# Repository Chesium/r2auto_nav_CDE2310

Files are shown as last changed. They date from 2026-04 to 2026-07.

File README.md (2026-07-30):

# CDE2310 System Engineering - AY2526 Group 3

- **Team Member:** Chen Shimin, Seow Cheng Si, Arnav Jhajharia, Abhinandan Shrimal, Daphne Shaine Wilhelmina
- **Final Grade: A-**

An autonomous TurtleBot3-based delivery robot built for the CDE2310/EG2310 robotics course at the National University of Singapore.

The robot was designed to explore an unknown maze, identify two target stations, dock using visual feedback, align a ping-pong-ball launcher with each receptacle, and fire three balls per station within a 25-minute mission window.

Course page: [CDE2310/EG2310 AY2526](https://blog.nus.edu.sg/eg2310/2026-2/)

## Final Run (14 April 2026, Week 13 Tue)

- [Final run screen recording, part 1](https://www.youtube.com/watch?v=hjtmTSh4A78)
- [Final run screen recording, part 2](https://www.youtube.com/watch?v=OZwQptIx55s)

The final run did not reflect the system we hoped to demonstrate. Our team ended up with the lowest final-run score, mainly because the frontier mapping and Nav2 mission flow did not come together reliably during full-system integration. That result was disappointing, but it also made the project a useful record of what worked, what did not, and what we would do differently.

Despite the difficult final demonstration, the project was still valuable. I eventually received an A- for the course, and I suspect the documentation and engineering reflection captured in this repository helped compensate for the weak final run. I entered the course without a Nav2 background, and the work here gave me practical experience with ROS 2 navigation, frontier exploration, simulation, robot networking, and system integration. That experience later helped me secure my first robotics-navigation internship at [Griffin Labs](https://griffinlabs.ai/). The course experience was rough, but the learning was real.

- Frontier Exploration Demo In Simulation (20 March 2026, Week 9 Fri)

https://github.com/user-attachments/assets/755e566e-a58e-4059-8860-4c8718844997

- Turtlebot Navigation Demo Video (21 March 2026, Week 9 Sat)

https://github.com/user-attachments/assets/281b9f60-19b3-4af7-8525-cc15e1a01227

## System Overview

The platform extends a TurtleBot3 Burger with a Raspberry Pi, LiDAR, USB/RPi camera sensing, a custom mechanical ball launcher, and ROS 2 software running across robot and laptop/container environments.

At a high level, the system is organized into:

| Layer | Main components | Purpose |
| --- | --- | --- |
| Mission control | `g3_mission_control` | Finite-state mission sequencing, retries, station tracking, launcher coordination |
| Navigation | Nav2, SLAM, `g3g_frontier_exploration`, `g3nav2` | Autonomous exploration, path planning, obstacle avoidance, hardware Nav2 configuration |
| Perception and docking | `g3_visual_servo`, ArUco markers, station aligners | Station detection, short-range docking, receptacle alignment |
| Actuation | `g3_ball_launcher`, TurtleBot3 motor control | UART servo-based ball launching and base motion |
| Simulation and assets | `g3gzsim`, Gazebo Harmonic worlds, CAD files | Local testing, subsystem validation, mechanical design references |

The final mission concept was:

1. Start the robot and verify required services.
2. Explore the unknown arena using frontier-based exploration.
3. Detect Station A or Station B using ArUco markers.
4. Pause exploration and dock using visual servoing.
5. Align the launcher to the receptacle.
6. Fire three ping-pong balls.
7. Resume exploration until both stations are completed.

## Repository Map

| Path | Description |
| --- | --- |
| [`src/g3_mission_control`](src/g3_mission_control) | Python FSM controllers for the competition mission and simplified debug flow |
| [`src/g3g_frontier_exploration`](src/g3g_frontier_exploration) | Frontier selection and Nav2 goal dispatch for autonomous exploration |
| [`src/g3_visual_servo`](src/g3_visual_servo) | ArUco marker detection, pose publishing, and visual-servo docking experiments |
| [`src/g3_aligner`](src/g3_aligner) | Station alignment nodes using camera feedback and Hough-circle style target detection |
| [`src/g3_ball_launcher`](src/g3_ball_launcher) | Ball launcher node and UART servo SDK |
| [`src/g3gzsim`](src/g3gzsim) | Gazebo worlds, models, RViz configs, and simulation launch files |
| [`src/g3nav2`](src/g3nav2) | Nav2 launch and configuration for TurtleBot3 hardware |
| [`docker`](docker) | Portable ROS 2 Jazzy, Gazebo, Nav2, and Foxglove development environment |
| [`docs`](docs) | Course report pages, development guide, user manual, and subsystem documentation |
| [`obsidian-vault`](obsidian-vault) | Additional architecture notes, package references, and how-to material |
| [`mech`](mech) | Mechanical photos, launcher videos, drawings, and CAD files |

## Quick Start

The recommended development path is the Docker environment, which provides ROS 2 Jazzy, Gazebo Harmonic, Nav2, Cartographer, Foxglove bridge, and TurtleBot3 dependencies.

```bash
docker compose build
docker compose -f docker-compose.yml -f docker-compose.wslg.yml up -d
docker compose -f docker-compose.yml -f docker-compose.wslg.yml exec dev bash
```

Inside the container:

```bash
cd ~/nav_ws
colcon build --symlink-install
source install/setup.bash
ros2 launch g3gzsim nav2full_test_launch.py
```

To activate frontier exploration from another terminal:

```bash
ros2 service call /exploration/set_enabled std_srvs/srv/SetBool "{data: true}"
```

For host-specific setup, real-robot networking, camera launch commands, Foxglove, and Nav2 notes, see the [Development Guide](docs/DevelopmentGuide.md).

## Project Artifacts

- [User Manual](docs/assets/g2-report/Group3_User_Manual.pdf)
- [Development Guide](docs/DevelopmentGuide.md)
- [Architecture Overview](obsidian-vault/architecture/Architecture%20Overview.md)
- [ROS 2 Topic and Service Map](obsidian-vault/architecture/ROS2%20Topic%20and%20Service%20Map.md)
- [Package Index](obsidian-vault/packages/Package%20Index.md)

## Report Pages

- [Requirement Specifications](docs/G2-Requirement-Specifications.md)
- [Con-Ops](docs/G2-Con-Ops.md)
- [High-Level Design](docs/G2-High-Level-Design.md)
- Subsystem Design
  - [Launcher & Servo](docs/G2-Launcher-Servo.md)
  - [Visual Servo & ArUco Docking](docs/G2-Visual-Servo.md)
  - [Autonomous Exploration and Navigation](docs/G2-Autonomous-Exploration-and-Navigation.md)
  - [Receptacle Alignment](docs/G2-Alignment.md)
- [Interface Control Document](docs/G2-Interface-Control-Document.md)
- [Software Development Documentation](docs/G2-Software-Development-Documentation.md)
- [Testing Documentation](docs/G2-Testing-Documentation.md)
- [Areas for Improvement](docs/G2-Areas-for-Improvement.md)

## Mechanical Media

- [Front view](mech/front_view.jpg)
- [Back view](mech/back_view.jpg)
- [Side view](mech/side_view.jpg)
- [Launcher in action](mech/launcher_in_action.mp4)
- [Cam animation](mech/cam_animation.mp4)
- [Mechanical drawings](mech/drawings)
- [CAD files](mech/cad_files)

## Retrospective

Our early progress was stronger than the final result suggests. The team started ahead of average in preparation, assignments, and initial subsystem work. The navigation stack was completed and tested relatively early, and the project also produced a large amount of documentation, simulation work, CAD, and subsystem code.

The main weakness was integration. From around the Preliminary Design Review onward, subsystem maturity and integration pace slowed. Several modules remained too isolated for too long, and we overestimated how naturally the final system would come together. When the final run arrived, the integration quality was not strong enough for the navigation, docking, alignment, and launching chain to perform reliably as one system.

The biggest lessons:

- Treat integration as a first-class task from the beginning, not a final-week activity.
- Define interface specifications, ownership boundaries, and system-level test plans early.
- Prototype a thin end-to-end mission flow before polishing individual subsystems.
- Hold more frequent technical design reviews and reallocate support when a subsystem falls behind.
- Set up Docker, ROS 2 networking, and lab debugging infrastructure early so everyone can test independently.
- Complete the full CAD assembly earlier, including electronics placement and mounting details, to reduce late mechanical redesigns.

The result was imperfect, but the repository preserves both the engineering attempt and the learning process behind it.

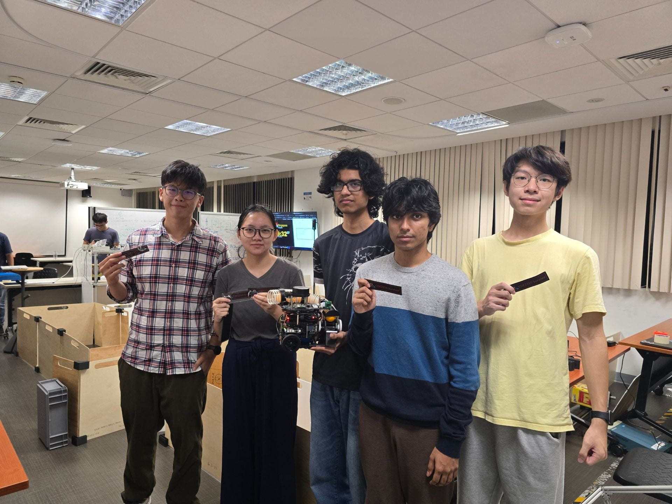
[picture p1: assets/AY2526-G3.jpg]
CDE2310 AY2526 Group 3 robot


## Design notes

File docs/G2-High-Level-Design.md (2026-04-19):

# High-Level Design

[Home](../README.md)

## Overall System Architecture

### Hardware and Electrical System Architecture

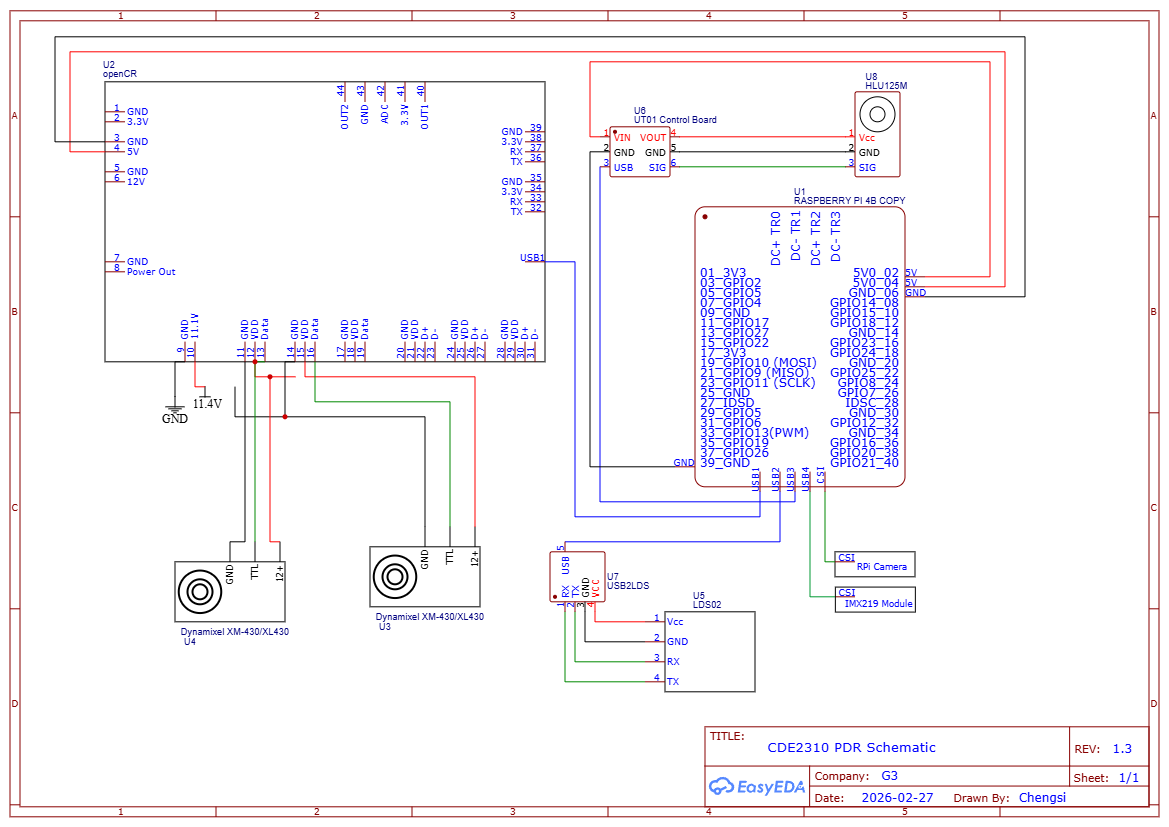
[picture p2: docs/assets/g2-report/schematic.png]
schematic


<p align="center">Fig: System schematic</p><br>

The hardware platform is based on a TurtleBot3 mobile base extended with onboard compute, camera sensing, launcher actuation, and supporting electrical subsystems. Power and signal routing are distributed across the Raspberry Pi, the OpenCR motor controller, and the attached peripheral devices. This modular arrangement allowed individual subsystems to be developed, tested, and replaced with minimal impact on the rest of the platform.

### Software Architecture

The software stack follows a modular ROS 2 node-based architecture. A central mission controller coordinates overall task sequencing, while specialised worker nodes handle docking, receptacle alignment, exploration, perception, and ball launching. The nodes communicate through ROS 2 topics and services, allowing each subsystem to be developed independently while maintaining clear runtime interfaces.

## Mission Logic Architecture Selection

An initial Behaviour Tree implementation using Groot2 and BehaviorTree.CPP was evaluated during early development. However, the final mission requirements were largely sequential and required limited interruption or dynamic replanning. In practice, the Behaviour Tree approach introduced additional implementation overhead, debugging complexity, and tooling instability relative to the project timeline.

The team therefore migrated to a Python-based finite state machine (FSM). This choice provided deterministic execution, faster implementation, and a simpler debugging workflow, while still matching the fixed sequence of tasks required by the competition.

## Mission Controller Design

### Overview

The mission controller (`mission_controller.py`) is the sole decision-making authority in the system. All other nodes act as specialised workers that publish observations or respond to service requests. The FSM runs at 10 Hz and coordinates the full delivery sequence across both stations. Long-range navigation is handled through exploration and Nav2, while close-range docking is delegated to the visual-servo subsystem based on ArUco pose estimation.

### FSM Graph

State flow: `INIT → EXPLORE → DOCK_AT_X → ALIGN_AT_X → FIRE_AT_X → COMPLETE`, with fallback transitions into `FAILED` for retry handling.

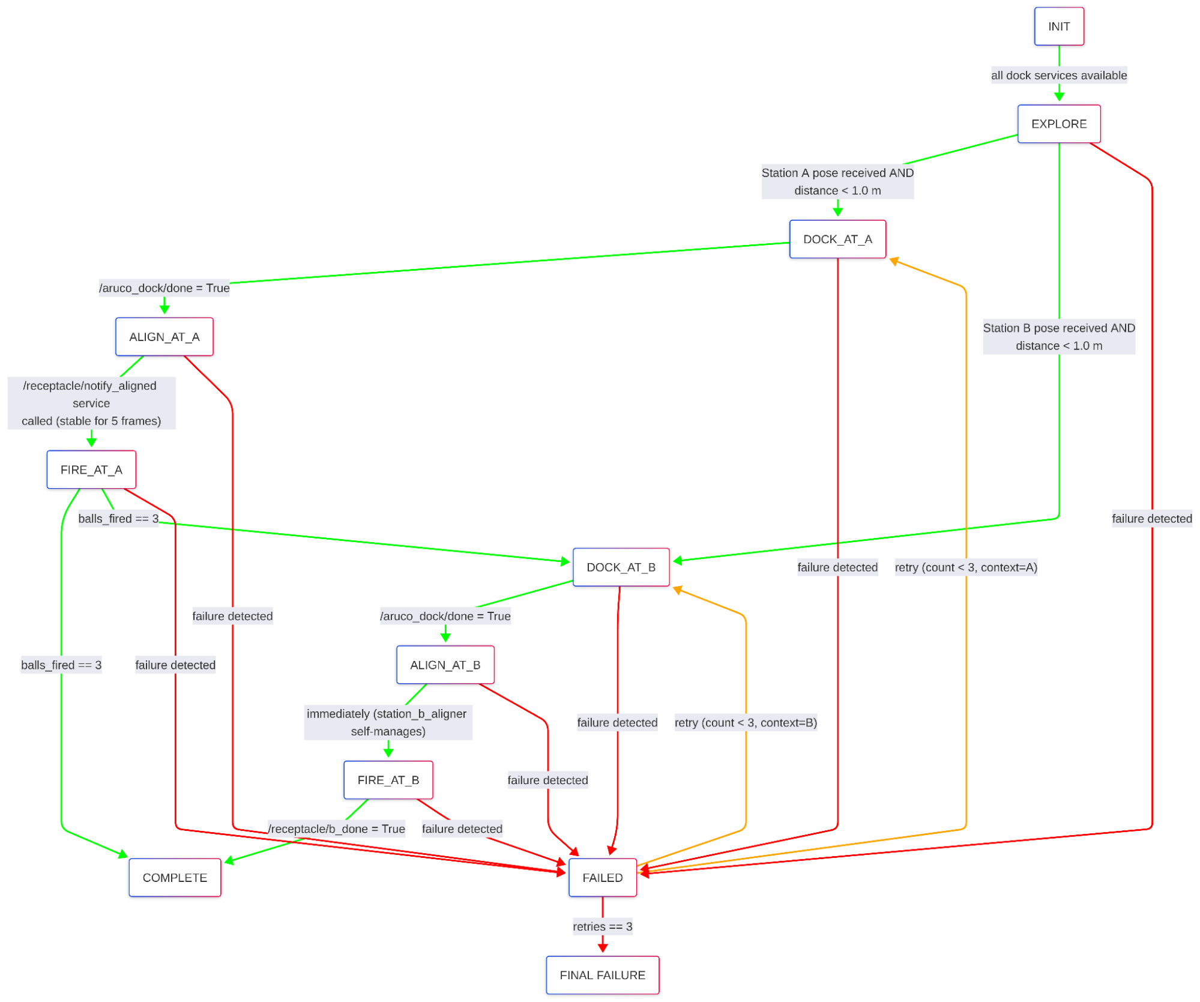
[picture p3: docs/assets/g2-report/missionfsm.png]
missionfsm


<p align="center">Fig: High-level mission controller FSM</p><br>

### Design Decisions and Rationale

| Decision | Rationale |
| --- | --- |
| Use visual servoing rather than Nav2 for final docking | Final approach is a short-range perception problem. ArUco-based visual servoing is less dependent on global localisation quality and avoids compounding map and pose error close to the target. |
| Run the FSM at 10 Hz rather than as a purely event-driven system | A fixed control tick simplifies timeout handling, keeps state transitions predictable, and reduces the likelihood of callback-order race conditions. |
| Allow Station B to trigger firing autonomously | The moving target at Station B requires a reactive trigger based on LED visibility. This response is more reliable when handled directly by the aligner than by a slower supervisory loop. |
| Expose timing values as ROS 2 parameters | Timing constraints changed during development. Parameterisation allowed the team to update mission behaviour without editing code or rebuilding the software stack. |

### Fault Handling and Robustness Strategy

The mission controller incorporates timeout detection, retry limits, and fallback transitions. If docking or alignment fails repeatedly at a given station, the controller can skip that station and continue with the remaining objectives where possible. This design reduces the risk that a single subsystem failure will terminate the entire mission.

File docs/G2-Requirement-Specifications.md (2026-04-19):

# Requirement Specifications

[Home](../README.md)

The G2 mission allocates 25 minutes for setup, execution, and teardown. During the setup period, the team must place the required identification markers, position the robot in the start zone, prepare the operator computer and software stack, load the ping-pong balls, and complete any other pre-run activities. A user guide must also be provided for the teaching staff's reference. Once activated, the autonomous mobile robot must leave the start zone, enter the maze, build a map using LiDAR, and detect the landmarks required for task execution.

The robot must identify two primary stations, Station A (static) and Station B (dynamic), using the markers placed during setup. It must then dock within operational tolerance, align its launcher, and deliver three ping-pong balls to each receptacle. The platform must carry at least nine ping-pong balls, and it may retry a shot if an unloading error occurs. At Station A, the robot must fire into a fixed receptacle of approximately 65 mm radius using a specified timing pattern. At Station B, the target receptacle moves on a motorised linear rail, so the robot must identify the marker, infer the motion timing, and coordinate docking and firing accordingly. After completing delivery, the robot must either continue to the next objective or conclude the mission. Official mission timing stops once the second unloading task is completed.

The bonus mission extends the task to Stations C and D. For this stage, the robot must navigate to the lift lobby using land-based QR markers, detect Station C, issue the required API call to summon the lift, enter the lift safely after arrival is confirmed, and send the appropriate command to travel to Level 2. It must then leave the lift, navigate to Station D, and unload into a fixed receptacle. At the end of the 25-minute window, the team must clear all materials from the arena. Scoring is based not only on payload delivery, but also on completion time and map closure, with additional credit awarded for single-launch ROS 2 deployment and ROS bag recording.

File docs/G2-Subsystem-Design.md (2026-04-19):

# Subsystem Design

[Home](../README.md)

## Launcher & Servo

The ball launcher uses a 25 kg-cm JOHO UART bus servo operated in DC motor mode, controlled by the `ball_launcher_node.py` in the `g3_ball_launcher` package. The node communicates with the servo over a USB-to-UART adapter at 115200 bps using a bundled Python SDK (`uart_sdk/`) that implements the JOHO packet protocol. On startup, the node sets the servo to DC mode (`MOTOR_MODE_DC = 0x00`), spins CW at low speed to find the init position (`CURRENT_POSITION = 4000`), then stops and reports idle. When /fire_launcher is called, a daemon thread calls `dc_rotate(CW, 100%)` to spin the motor at full PWM for 2.2 seconds, then `dc_stop()` to stop the motor. The status cycles through `idle → firing → complete → idle`, with the complete state held briefly so the mission controller can read it via the /launcher_status topic at 10 Hz. Thread safety is handled with two locks (`_lock` for status, `_serial_lock` for UART) and a `threading.Event` for stop requests.

Mechanical Subsystem Drawings

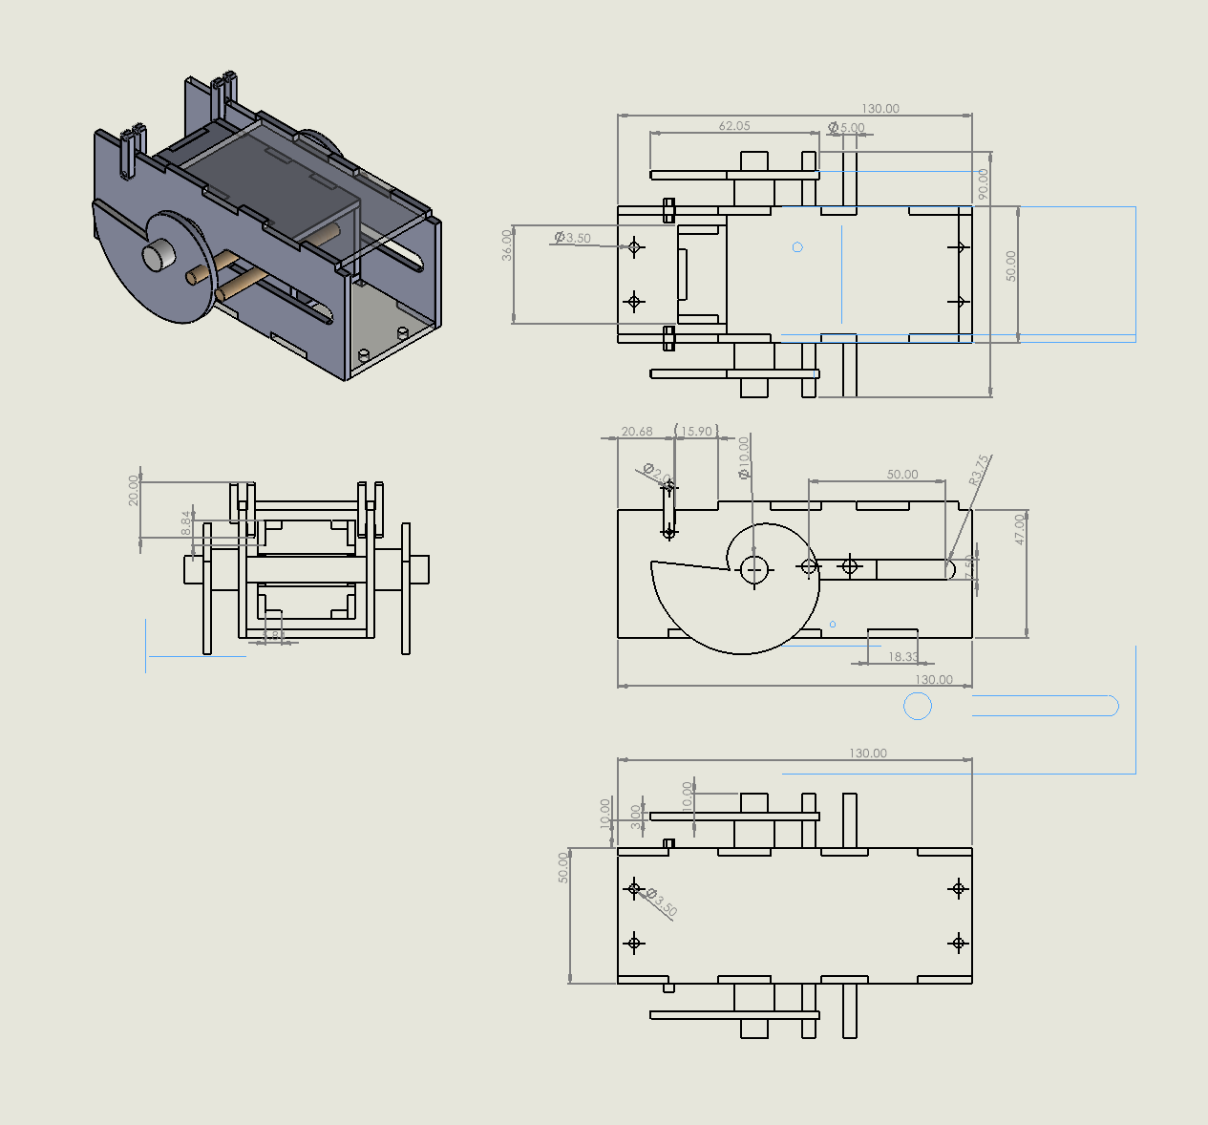
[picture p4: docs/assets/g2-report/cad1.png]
cad1


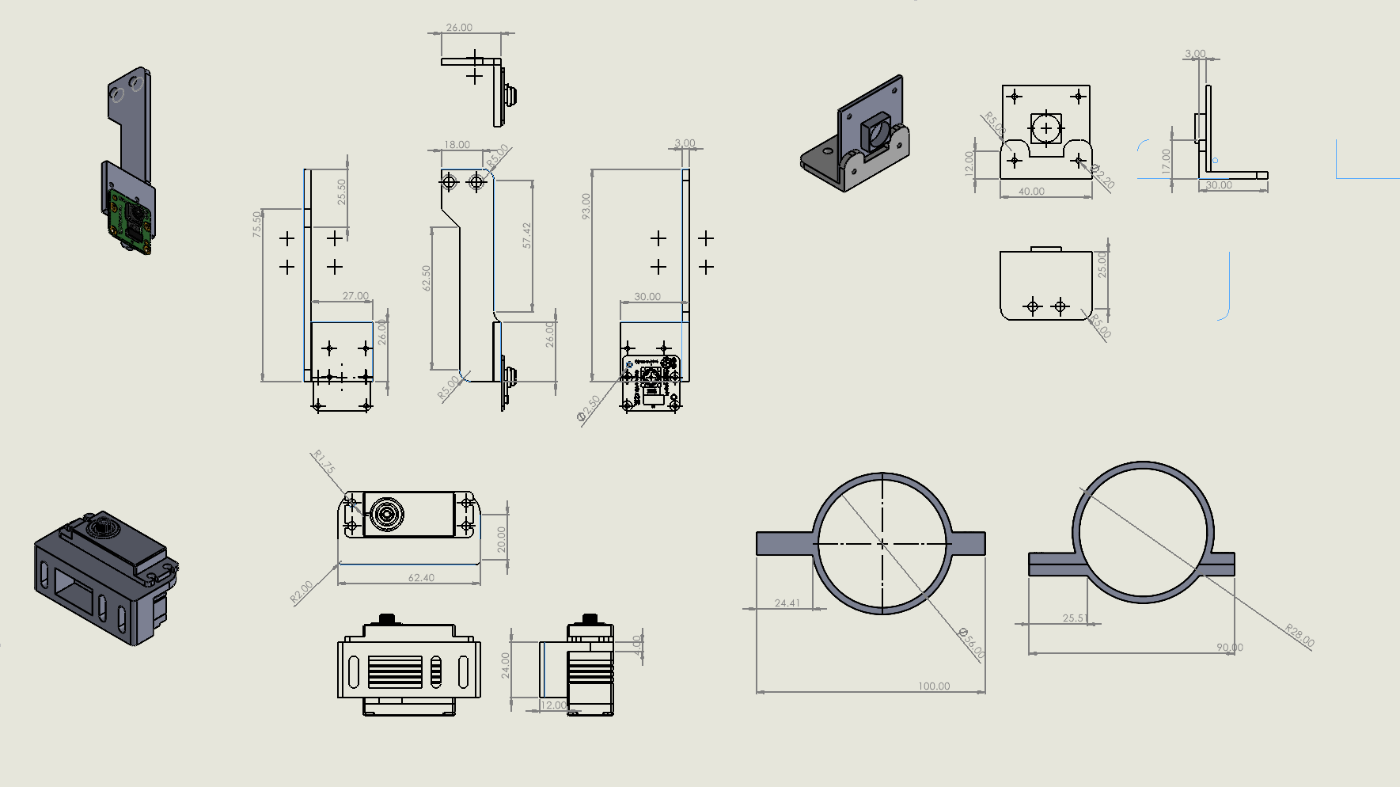
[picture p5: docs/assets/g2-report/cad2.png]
cad2


## Visual Servo/ Aruco Docking

### Overview

The algorithm uses solvePnP to do thi

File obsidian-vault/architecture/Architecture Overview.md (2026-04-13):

# Architecture Overview

## System Layers

```
┌─────────────────────────────────────────────────────┐
│                   MISSION LAYER                      │
│  mission_controller / simple_mission_fsm             │
│  (orchestrates the entire operation)                 │
├─────────────────────────────────────────────────────┤
│                 PERCEPTION LAYER                     │
│  aruco_dock_node     station_a_aligner               │
│  (camera → marker    (camera → Hough circle          │
│   detection + servo)  detection + P-control)          │
├─────────────────────────────────────────────────────┤
│                 NAVIGATION LAYER                     │
│  Nav2 stack          frontier_explorer               │
│  (path planning,     (autonomous exploration         │
│   obstacle avoid)     of unknown space)               │
├─────────────────────────────────────────────────────┤
│                  ACTUATION LAYER                     │
│  ball_launcher_node  /cmd_vel → motors               │
│  (UART servo for     (TurtleBot3 motor driver)       │
│   ball shooting)                                     │
├─────────────────────────────────────────────────────┤
│                  HARDWARE/SIM                        │
│  TurtleBot3 Burger   Gazebo Harmonic                 │
│  RPi + LiDAR + USB   (simulated world + sensors)     │
│  camera + servo                                      │
└─────────────────────────────────────────────────────┘
```

## Node Communication Graph

```mermaid
graph TB
    subgraph Mission
        MC[mission_controller]
        SFSM[simple_mission_fsm]
    end
    
    subgraph Perception
        ADN[aruco_dock_node]
        APP[aruco_dock_pose_publisher]
        SA[station_a_aligner]
    end
    
    subgraph Navigation
        NAV2[Nav2 Stack<br/>planner/controller/BT]
        FE[frontier_explorer]
        DS[docking_server]
    end
    
    subgraph Actuation
        BL[ball_launcher_node]
    end
    
    subgraph Sensors
        CAM[USB Camera]
        LIDAR[LiDAR]
    end
    
    CAM -->|/usb_cam/image_raw| ADN
    CAM -->|/camera/image_raw| APP
    CAM -->|/camera/image_raw/compressed| SA
    LIDAR -->|/scan| NAV2
    
    ADN -->|/station_a_pose<br/>/station_b_pose| MC
    ADN -->|/station_a_pose| SFSM
    ADN -->|/aruco_dock/done| SFSM
    ADN -->|/cmd_vel| Motors
    
    APP -->|/detected_dock_pose| DS
    
    SA -->|/receptacle/offset<br/>/receptacle/aligned| MC
    SA -->|/cmd_vel| Motors
    
    MC -->|NavigateToPose action| NAV2
    MC -->|/fire_launcher service| BL
    
    SFSM -->|/exploration/set_enabled| FE
    SFSM -->|/aruco_dock/dock_to_a| ADN
    
    FE -->|NavigateToPose action| NAV2
    
    BL -->|/launcher_status| MC
```

## Two Mission Controller Variants

### 1. `mission_controller.py` (Full competition FSM)
- Written by Daphne
- Handles: Explore -> Navigate -> Align -> Fire -> repeat
- Uses Hough circle alignment (`station_a_aligner`)
- Controls ball firing with timing delays
- 11 states, retry logic, full competition flow

### 2. `simple_mission_fsm.py` (Teaching/debug FSM)
- Minimal 4-state FSM: INIT -> EXPLORE -> DOCK -> DONE
- Coordinates frontier_explorer + aruco_dock_node
- Clean example of FSM design patterns
- Good for understanding the system without competition complexity

## Two Docking Approaches

### Legacy: `aruco_dock_node.py`
- Custom PI control loop
- Publishes `/cmd_vel` directly
- States: IDLE -> SCANNING -> APPROACHING -> DONE
- Triggered via `/aruco_dock/dock_to_a` service

### New (Nav2): `aruco_dock_pose_publisher.py` + `docking_server`
- Just publishes marker pose to `/detected_dock_pose`
- Nav2's `opennav_docking` handles the actual approach
- Uses `SimpleNonChargingDock` plugin
- Triggered via `/dock_robot` action

---

**See also:** [[ROS2 Topic and Service Map]], [[State Machine Reference]]

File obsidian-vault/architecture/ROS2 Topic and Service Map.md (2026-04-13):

# ROS2 Topic and Service Map

## Topics

### Perception Topics

| Topic | Type | Publisher | Subscriber | Purpose |
|---|---|---|---|---|
| `/station_a_pose` | PoseStamped | aruco_dock_node | mission_controller, simple_mission_fsm | Robot's map-frame pose when marker 42 seen |
| `/station_b_pose` | PoseStamped | aruco_dock_node | mission_controller | Robot's map-frame pose when marker 67 seen |
| `/detected_dock_pose` | PoseStamped | aruco_dock_pose_publisher | Nav2 docking_server | Marker pose in camera frame for Nav2 docking |
| `/aruco_dock/done` | Bool | aruco_dock_node | simple_mission_fsm | Docking approach complete signal |
| `/aruco_debug/image_raw` | Image | aruco_dock_node | Foxglove | Debug overlay with marker detection |
| `/receptacle/offset` | Int32 | station_a_aligner | mission_controller | Pixel offset from center (9999 = not detected) |
| `/receptacle/aligned` | Bool | station_a_aligner | mission_controller | True when Hough circle centered |
| `/receptacle/tin_ready` | Bool | station_a_aligner | mission_controller | Same as aligned for Station A |
| `/receptacle/annotated` | Image | station_a_aligner | Foxglove | Debug overlay with Hough detection |

### Navigation Topics

| Topic | Type | Publisher | Subscriber | Purpose |
|---|---|---|---|---|
| `/cmd_vel` | TwistStamped or Twist | Nav2/aruco_dock/aligner | motor driver | Velocity commands |
| `/map` | OccupancyGrid | SLAM (Cartographer) | frontier_explorer, Nav2 | Occupancy grid map |
| `/scan` | LaserScan | LiDAR driver | SLAM, Nav2 costmaps | 2D laser scans |
| `/odom` | Odometry | motor driver | Nav2, SLAM | Wheel odometry |
| `/exploration/frontiers` | MarkerArray | frontier_explorer | RViz | Visualization of frontier cells |
| `/exploration/current_goal` | PoseStamped | frontier_explorer | RViz | Current exploration target |

### State/Status Topics

| Topic | Type | Publisher | Subscriber | Purpose |
|---|---|---|---|---|
| `/mission_state` | String | mission_controller / simple_mission_fsm | monitoring | Current FSM state name |
| `/launcher_status` | String | ball_launcher_node | mission_controller | "idle"/"firing"/"complete"/"error" |
| `/exploration_complete` | Bool | frontier_explorer | mission_controller | All stations found signal |

### Camera Topics

| Topic | Type | Source | Notes |
|---|---|---|---|
| `/usb_cam/image_raw` | Image | USB camera (hardware) | Used by aruco_dock_node |
| `/usb_cam/camera_info` | CameraInfo | USB camera (hardware) | Camera intrinsics |
| `/camera/image_raw` | Image | Gazebo camera (sim) | Used by aruco_dock_pose_publisher |
| `/camera/camera_info` | CameraInfo | Gazebo camera (sim) | Camera intrinsics |
| `/camera/image_raw/compressed` | CompressedImage | RPi camera | Used by station_a_aligner |

---

## Services

| Service | Type | Server | Client | Purpose |
|---|---|---|---|---|
| `/fire_launcher` | Trigger | ball_launcher_node | mission_controller | Request one ball shot |
| `/stop_launcher` | Trigger | ball_launcher_node | operator | Emergency stop motor |
| `/aruco_dock/dock_to_a` | Trigger | aruco_dock_node | simple_mission_fsm | Start docking to marker 42 |
| `/aruco_dock/dock_to_b` | Trigger | aruco_dock_node | mission_controller | Start docking to marker 67 |
| `/aruco_dock/scan` | Trigger | aruco_dock_node | operator | Return to passive scanning |
| `/exploration/set_enabled` | SetBool | frontier_explorer | simple_mission_fsm | Enable/disable exploration |

---

## Actions

| Action | Type | Server | Client | Purpose |
|---|---|---|---|---|
| `/navigate_to_pose` | NavigateToPose | Nav2 BT navigator | mission_controller, frontier_explorer | Point-to-point navigation |
| `/compute_path_to_pose` | ComputePathToPose | Nav2 planner | frontier_explorer | Path feasibility check |
| `/dock_robot` | DockRobot | Nav2 docking_server | operator (manual test) | Nav2 docking action |

---

## QoS Notes

- `/station_a_pose` and `/station_b_pose` use **TRANSIENT_LOCAL** (latched) QoS
  - Subscribers MUST match this or messages silently drop
  - `simple_mission_fsm` correctly uses latched QoS for `/station_a_pose`
- `/map` uses TRANSIENT_LOCAL from SLAM
- Camera topics from Gazebo bridge use default RELIABLE
- RPi compressed camera uses BEST_EFFORT (matched in station_a_aligner)

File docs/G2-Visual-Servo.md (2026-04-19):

# Visual Servo and ArUco Docking Subsystem

[Home](../README.md)

## Overview

The docking subsystem is responsible for bringing the robot from a "marker detected somewhere ahead" state into a fixed, repeatable pose in front of each station so the launcher can engage the receptacle. It is implemented as a single ROS 2 node, `simple_aruco_dock.py` (`SimpleArucoDock`), in the `g3_visual_servo` package. The node does visual servoing directly from camera pixels to `/cmd_vel`, without Nav2 actions, TF lookups, or station frames — only the marker pose in the camera frame and a PI loop on top of it. A service call (`/aruco_dock/dock_to_a` or `/aruco_dock/dock_to_b`) triggers the approach; completion is reported on `/aruco_dock/done`.

### Docking Test Infrastructure

To tune parameters and verify the integration between docking and exploration, we built a lightweight custom dashboard used during early development. The dashboard streamed the left/front/right camera feeds, lidar view, and live odometry alongside a teleop joystick and navigation presets, which let us exercise the docking approach without having to bring up the full RViz/Nav2 stack.

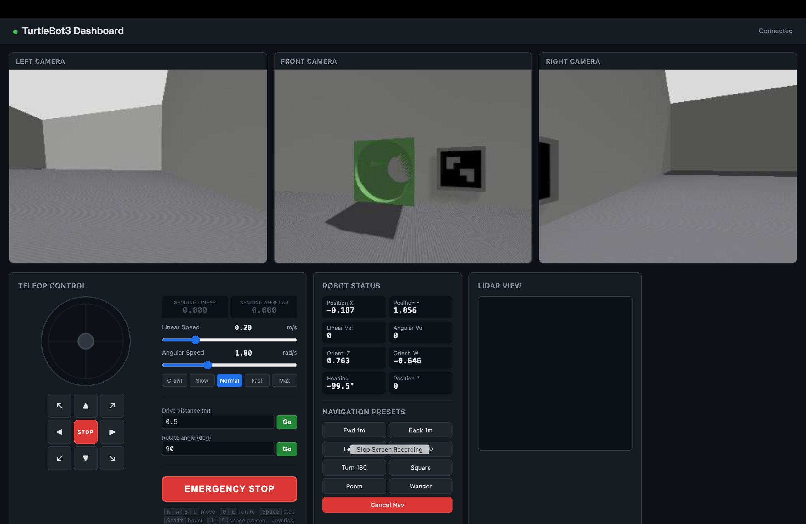
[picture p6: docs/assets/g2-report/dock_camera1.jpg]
dock_camera1


*TurtleBot3 Dashboard — used for early-stage docking tests, with left/front/right camera feeds, teleop, and robot state alongside the ArUco marker visible in the front camera during approach.*

We later migrated to Foxglove for simulation and on-robot debugging, publishing annotations on a debug topic (`/aruco_debug`, plus a compressed debug image on `/aruco_debug/image_raw/compressed`) so that each stage of the docking FSM and every PnP detection could be visualised in real time. The debug image overlays the detected marker, the pose axes from `solvePnP`, and a live readout of distance, heading, and `tvec`, while a side panel shows the active docking state (e.g. `LOCKING`, `APPROACHING`, `POST_TURN`, `POST_SHIFT`).

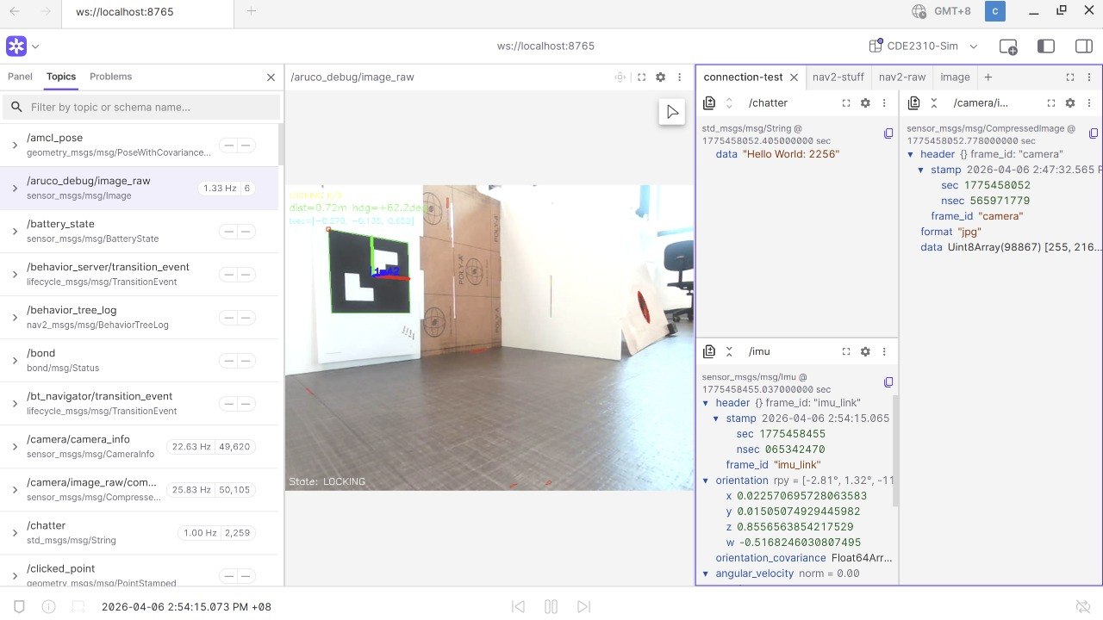
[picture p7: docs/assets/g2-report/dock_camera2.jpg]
dock_camera2


*Foxglove debugging layout showing `/aruco_debug/image_raw` with PnP overlay (`dist=0.72 m, hdg=+62.2°, tvec=...`) and the live docking FSM state in the bottom-left corner.*

### Methods Considered

The docking approach went through two notable iterations:

1. **QR → ArUco fiducials.** An early prototype used QR code fiducials for station anchoring. We switched to ArUco markers because of their simplicity, faster detection, and lower computational overhead — the same rationale given in our ConOps and PDR documents.
2. **Nav2 docking (Week 12).** We briefly evaluated the Nav2 `opennav_docking` server, which would have provided collision-aware staging and tighter integration with the existing Nav2 stack. The scaffolding for this path still lives on the [`feat/nav2-docking`](https://github.com/Chesium/r2auto_nav_CDE2310/tree/feat/nav2-docking) branch — a `SimpleChargingDock` plugin wrapper ([`aruco_dock_node.py`](https://github.com/Chesium/r2auto_nav_CDE2310/blob/feat/nav2-docking/src/g3_visual_servo/g3_visual_servo/aruco_dock_node.py)), an ArUco pose publisher into the `map` frame ([`aruco_dock_pose_publisher.py`](https://github.com/Chesium/r2auto_nav_CDE2310/blob/feat/nav2-docking/src/g3_visual_servo/g3_visual_servo/aruco_dock_pose_publisher.py)), a `DockRobot` action client ([`dock_action_client.py`](https://github.com/Chesium/r2auto_nav_CDE2310/blob/feat/nav2-docking/src/g3_visual_servo/g3_visual_servo/dock_action_client.py)), bring-up launch files ([`aruco_dock.launch.py`](https://github.com/Chesium/r2auto_nav_CDE2310/blob/feat/nav2-docking/src/g3_visual_servo/launch/aruco_dock.launch.py), [`aruco_dock_hw_test.launch.py`](https://github.com/Chesium/r2auto_nav_CDE2310/blob/feat/nav2-docking/src/g3_visual_servo/launch/aruco_dock_hw_test.launch.py), [`nav2_docking_sim_test.launch.py`](https://github.com/Chesium/r2auto_nav_CDE2310/blob/feat/nav2-docking/src/g3gzsim/launch/nav2_docking_sim_test.launch.py)), tuned Nav2 parameters ([`g3_nav2_params.yaml`](https://github.com/Chesium/r2auto_nav_CDE2310/blob/feat/nav2-docking/src/g3nav2/config/g3_nav2_params.yaml)), and a mission FSM variant that drove the DockRobot action ([`nav2_mission_fsm.py`](https://github.com/Chesium/r2auto_nav_CDE2310/blob/feat/nav2-docking/src/g3_mission_control/g3_mission_control/nav2_mission_fsm.py)). However, OpenCR firmware and low-level communication issues consumed a large portion of the integration window. By the time the base was responding reliably to velocity commands, there was not enough time left to properly configure the dock plugin and tune its controller for our drivetrain. Rather than introduce a half-integrated dependency on the critical path, we committed to the direct ArUco visual-servo approach that we could build, tune, and debug end-to-end ourselves.

### Camera Implementation

The camera is an **IMX219-120 4-Lane 8 MP** MIPI CSI-2 module (Sony IMX219 sensor, 120° diagonal FOV wide-angle lens, ~0.66 W @ 3.3 V per the power budget). The wide FOV was important: it kept the ArUco marker inside the frame during the final close-range approach, where a narrower lens would have lost the marker just as the PI loop needed it most. The module is driven through `ros-jazzy-usb-cam` as a V4L2 source, publishing `sensor_msgs/Image` on `/usb_cam/image_raw` and `sensor_msgs/CameraInfo` on `/usb_cam/camera_info`. Because of the wide-angle distortion we ran a full intrinsic calibration with the standard `camera_calibration` checkerboard pipeline; the resulting `K` matrix and distortion vector are cached once in `_info_cb` and reused for `solvePnP`. Without this calibration the marker-distance estimate is biased by several centimetres — well over our 4 cm docking tolerance.

We use the 4×4 ArUco dictionary (`DICT_4X4_100`) with a physical marker size of 38 mm. Corner detection runs with subpixel refinement (`CORNER_REFINE_SUBPIX`, 5 px window, 30 iterations), because at 30 cm range a 1-pixel corner error translates into a noticeable bearing and distance error.

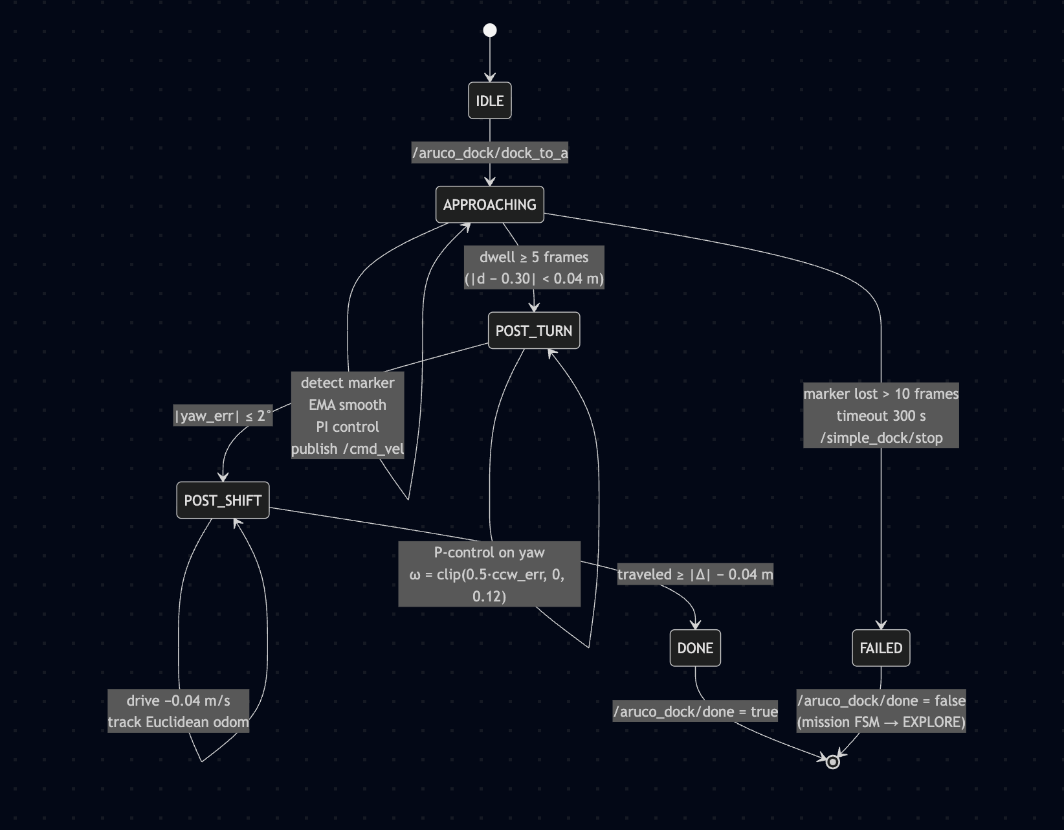
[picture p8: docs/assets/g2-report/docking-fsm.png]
dock_camera1


### Runtime Deployment

The docking node was run off-board on the host laptop rather than on the TurtleBot3's Raspberry Pi, with ROS 2 discovery handled by the **FastDDS Discovery Server** so the laptop and the Pi could reliably see each other's topics across the lab network. Two considerations drove this split:

- **Thermals on the Pi.** Running the full OpenCV + ArUco + PnP pipeline on the Raspberry Pi caused sustained CPU load and noticeable thermal throttling during longer test runs. Offloading the perception and control loop to the laptop kept the Pi cool enough to focus on `usb_cam`, `turtlebot3_bringup`, and the OpenCR bridge.
- **Image transport latency.** We measured the end-to-end latency of streaming `/usb_cam/image_raw` from the Pi to the laptop over the Discovery Server link and found it low enough (well under one control tick) that it did not meaningfully degrade the closed-loop docking performance.

The node itself was launched with a plain `ros2 run g3_visual_servo simple_aruco_dock`, which kept the iteration loop (edit parameter → restart → re-test) short during tuning.

### Detection and Pose Estimation

Each frame, `_image_cb`:

1. Converts the image with `cv_bridge` and grayscales it.
2. Runs `aruco.detectMarkers` once, splitting the result into two uses: a passive scan that republishes the station pose on `/station_a_pose` whenever a known marker is visible, and an active-approach branch that matches the commanded target ID.
3. Estimates pose with `cv2.solvePnP` using `SOLVEPNP_IPPE_SQUARE`, a solver designed for planar square markers that is faster and more stable than the generic iterative solver at close range.
4. Derives from `tvec`: bearing = `atan2(tx, tz)`, distance = `tz − camera_forward_offset` (the camera sits 8 cm ahead of `base_link`, so the controller stops the *robot*, not the *camera*, at 30 cm from the marker), lateral offset = `tx`, and marker-normal yaw from `cv2.Rodrigues(rvec)`.

### Control Algorithm

Inside the `APPROACHING` state, the control loop is:

- EMA smoothing (α = 0.3) on both bearing and distance so single-frame detection noise does not jerk the robot.
- Proportional angular control: `ωz = clip(−1.2 · bearing, ±0.05 rad/s)`.
- PI linear control on distance error: `Kp = 0.5`, `Ki = 0.08`, with anti-windup — the integrator advances only when the bearing is small (< 15°) and the output is not saturated. This prevents windup during the initial rotation when the robot is aligning but not yet driving.
- Output caps are deliberately tight: `max_linear = 0.02 m/s`, `max_angular = 0.05 rad/s`.

### Why We Chose Slow Docking

The tight speed cap is not cosmetic; it falls out of three hardware and perception constraints:

1. **Detection latency and EMA lag.** `usb_cam` delivers ~15 Hz, PnP adds a few ms, and the EMA is explicitly low-pass. Much faster than 2 cm/s and the robot overshoots before the smoothed distance catches up.
2. **Differential-drive deadband.** The TurtleBot's motors do not move reliably below roughly 0.015 m/s; a slightly higher ceiling gave us stick-slip where the robot would creep, stall, lurch, and repeat. The cap keeps the command just above the deadband.
3. **Stopping precision for the launcher.** Docking feeds directly into the ping-pong launcher, which needs the marker centred within a few centimetres. At 2 cm/s with a 4 cm tolerance, one controller tick of overshoot is within spec.

Completion requires the distance to be within tolerance for five consecutive frames (`dwell_frames = 5`), filtering out single-frame PnP spikes that would otherwise trigger a false DONE.

### Failure Handling

If the marker is lost briefly (< 3 frames) the robot coasts on the last command; between 3 and 10 frames it holds still; past 10 frames the approach fails. A 300 s timeout guards against deadlocks. On failure the node publishes `Bool(false)` on `/aruco_dock/done`; the mission controller uses this to reset back to `EXPLORE` rather than stalling.

### Post-Dock Sequence

Because the launcher is offset from the robot's front, the approach ends with a two-step alignment:

- **Post-turn** — rotate CCW so the marker normal ends up at −90° in the camera frame (wall on the robot's left). The turn magnitude is computed in the camera frame from `normal_yaw` and executed in the odom frame with a small P controller on yaw.
- **Post-shift** — after the turn the camera no longer sees the marker. The required shift is derived in closed form from the *remembered* pre-turn lateral offset and the turn angle:

  Δ = −x · sin(a) − r · (1 − cos(a))

  where `x` is the pre-turn lateral offset (`tvec[0]`), `a` is the turn angle, and `r` is the camera-to-base forward offset (0.08 m). Progress is tracked with Euclidean odom distance (not heading projection, which was brittle after the turn), stopping within a 4 cm tolerance.

Only after both post-steps complete does the node publish `done = true`, handing control back to the mission FSM.

### FSM Diagram

```mermaid
stateDiagram-v2
    [*] --> IDLE

    IDLE --> APPROACHING: /aruco_dock/dock_to_a

    APPROACHING --> APPROACHING: detect marker<br/>EMA smooth<br/>PI control<br/>publish /cmd_vel
    APPROACHING --> POST_TURN: dwell ≥ 5 frames<br/>(|d − 0.30| < 0.04 m)
    APPROACHING --> FAILED: marker lost > 10 frames<br/>timeout 300 s<br/>/simple_dock/stop

    POST_TURN --> POST_TURN: P-control on yaw<br/>ω = clip(0.5·ccw_err, 0, 0.12)
    POST_TURN --> POST_SHIFT: |yaw_err| ≤ 2°

    POST_SHIFT --> POST_SHIFT: drive −0.04 m/s<br/>track Euclidean odom
    POST_SHIFT --> DONE: traveled ≥ |Δ| − 0.04 m

    DONE --> [*]: /aruco_dock/done = true
    FAILED --> [*]: /aruco_dock/done = false<br/>(mission FSM → EXPLORE)
```

### Top-Level FSM

| # | State | Entered by | Actions | Exit condition | Next state |
| --- | --- | --- | --- | --- | --- |
| 1 | `IDLE` | Node startup or `/aruco_dock/scan` | Passive marker scan only; publish station pose when marker is seen | Service call `/aruco_dock/dock_to_a` | `APPROACHING` |
| 2 | `APPROACHING` | `_begin_approach()` resets EMAs, integrator, counters, timestamps | Detect target marker; EMA-smooth bearing & distance; run PI control; publish `/cmd_vel` | Dwell (5 frames within tolerance) → success; marker lost > 10 frames / 300 s timeout / stop service → failure | `POST_TURN` or `FAILED` |
| 3 | `POST_TURN` | Successful dwell in `APPROACHING` | 20 ms timer: P-controller on yaw toward `odom_yaw + a` | `\|yaw_err\| ≤ 2°` | `POST_SHIFT` |
| 4 | `POST_SHIFT` | Post-turn complete | 20 ms timer: drive backward at 0.04 m/s; track Euclidean odom distance | Traveled ≥ `\|Δ\| − 0.04 m` | `DONE` |
| 5 | `DONE` | Post-shift complete | Publish `Bool(true)` on `/aruco_dock/done` | — | Returns to `IDLE` on next service call |
| 6 | `FAILED` | Timeout / marker lost / stop | Stop robot; cancel post-timers | — | Publish `Bool(false)`; mission FSM returns to `EXPLORE` |

### Per-Frame Algorithm in `APPROACHING`

| Step | Operation | Key parameters / formula |
| --- | --- | --- |
| 1 | Receive `Image` on `/usb_cam/image_raw` | — |
| 2 | Convert to grayscale via `cv_bridge` | `bgr8 → GRAY` |
| 3 | Detect markers | `DICT_4X4_100`; subpixel refinement (5 px, 30 iter) |
| 4 | Passive scan — publish station pose when marker seen | `/station_a_pose` |
| 5 | Active detection — match target ID | `solvePnP` with `SOLVEPNP_IPPE_SQUARE`, marker size 38 mm |
| 6 | Compute measurements | `bearing = atan2(tx, tz)`; `distance = tz − 0.08`; `lateral = tx`; `normal_yaw` from `Rodrigues(rvec)` |
| 7 | Timeout check | Abort if elapsed > 300 s |
| 8 | EMA smoothing | α = 0.3 on bearing and distance |
| 9 | Dwell check (before control) | `\|d − 0.30\| < 0.04` or `d_raw ≤ 0.30` → `dwell_count++`; 5 in a row → DONE |
| 10 | Angular command | `ωz = clip(−1.2 · bearing, ±0.05 rad/s)` |
| 11 | Linear PI with anti-windup | `Kp = 0.5`, `Ki = 0.08`; integrate only if `\|bearing\| < 15°` and unsaturated; `vx = clip(PI, 0, 0.02 m/s)` |
| 12 | Hold if inside tolerance | If `d_ema ≤ 0.30 + 0.04`: `vx = ωz = 0`, reset integrator |
| 13 | Publish `/cmd_vel` (`TwistStamped`) | Frame `base_link` |
| 14 | Marker-loss policy | < 3 frames: coast; 3–10: stop & zero integrator; ≥ 10: FAIL |

### Post-Dock Sequence

| Stage | Purpose | Control loop (20 ms timer) | Completion |
| --- | --- | --- | --- |
| Post-turn | Orient wall to robot's left (marker normal → −90° in camera frame) | `ωz = clip(0.5 · ccw_err, 0, 0.12 rad/s)` toward `target_yaw = odom_yaw + a`, with `a = ccw_angle(normal_yaw, −90°)` | `\|yaw_err\| ≤ 2°` |
| Post-shift | Re-centre `base_link` on the marker after the turn | Drive at −0.04 m/s; track Euclidean odom distance | Traveled ≥ `\|Δ\| − 0.04 m`, where `Δ = −x·sin(a) − r·(1 − cos(a))`, `x = pre-turn tvec[0]`, `r = 0.08 m` |
| Publish done | Hand control back to mission FSM | `Bool(true)` on `/aruco_dock/done` | — |

### Key Parameters

| Parameter | Value | Meaning |
| --- | --- | --- |
| `marker_size` | 0.038 m | Physical side length of ArUco marker |
| `dictionary` | `DICT_4X4_100` | ArUco dictionary |
| `dock_distance` | 0.30 m | Target stop distance (robot to marker) |
| `dist_tolerance` | 0.04 m | Acceptable distance error |
| `camera_forward_offset` | 0.08 m | Camera optical centre ahead of `base_link` |
| `bearing_tolerance_deg` | 15° | Angular alignment tolerance |
| `dwell_frames` | 5 | Consecutive in-tolerance frames before DONE |
| `approach_timeout` | 300 s | Abort if not docked in time |
| `kp_angular / kp_linear / ki_linear` | 1.2 / 0.5 / 0.08 | Control gains |
| `max_linear / max_angular` | 0.02 m/s / 0.05 rad/s | Output caps (slow-dock policy) |
| `ema_alpha` | 0.3 | EMA smoothing factor |
| `lost_hold / lost_stop` | 3 / 10 frames | Marker-loss coast → stop → fail thresholds |
| `final_heading_offset_deg` | −90° | Target marker-normal angle after post-turn |
| `post_turn_speed / post_turn_kp` | 0.12 rad/s / 0.5 | Post-turn controller |
| `post_shift_speed / post_shift_distance_tolerance` | 0.04 m/s / 0.04 m | Post-shift controller |

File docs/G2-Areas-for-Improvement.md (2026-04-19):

# Areas for Improvement

[Home](../README.md)

## Early System Integration and Compute Resource Planning

Several issues would likely have been detected earlier if all major nodes had been integrated onto the physical robot sooner, even with limited functionality. Earlier full-system testing would have exposed power limitations, CPU contention, interface mismatches, and timing conflicts well before the final mission. During operation, running docking, perception, alignment, and launcher nodes concurrently placed significant computational load on the Raspberry Pi. Future iterations should either migrate heavier vision workloads to a more capable onboard computer or optimise the existing nodes more aggressively to reduce latency and dropped frames.

## Power Management and Electrical Safety

Power management proved to be a major operational concern. The TurtleBot3 battery discharged quickly during repeated motion tests, reducing test duration and occasionally contributing to unstable system behaviour. Future operation should include scheduled charging cycles, spare battery availability, and the use of bench power during development tasks that do not require motor actuation.

Electrical handling procedures also require improvement. Hardware damage occurred due to wiring mistakes and mechanical work performed near powered electronics. Future builds should adopt stricter power-off maintenance procedures, connector polarity checks, and a pre-power inspection checklist.

## Mechanical Readiness Before Software Tuning

The robot's mechanical platform should be finalised before advanced software tuning begins. Structural looseness, vibration, and wobble degraded localisation, exploration, and navigation performance. A mechanically stable platform provides a more reliable baseline for electrical integration, controller tuning, and perception calibration.

## Simplicity-First Engineering Strategy

Future teams should prioritise robust and simple solutions that satisfy mission requirements before pursuing more ambitious designs. Several sophisticated approaches consumed significant debugging time and delayed system integration. A more effective strategy is to establish a reliable minimum viable system first, then improve performance incrementally once end-to-end mission functionality has been demonstrated.

## Navigation Reliability, Time Synchronisation, and Mechanical Stability

One major area for improvement is the robustness of the navigation system when deployed as a distributed ROS 2 stack across the TurtleBot Raspberry Pi and the operator laptop. In the final architecture, low-level odometry and scan data originated on the Raspberry Pi, while Cartographer and Nav2 ran on the laptop. This made the navigation pipeline highly sensitive to cross-device timing consistency because `odom` and `map -> odom` were generated on different machines.

### Observed Symptoms

During testing, the robot occasionally moved unusually slowly after receiving a Nav2 goal and exhibited visible side-to-side swaying. RViz continued to display plausible global routes, so the issue did not initially appear to be a straightforward global-planning failure. Several days before the final run, intermittent goal aborts were also observed. Nav2 logs repeatedly reported `Lookup would require extrapolation into the future` when resolving transforms between `map` and `odom`, with timing gaps on the order of tens of milliseconds.

During the final run, both problems became more severe. The robot could not maintain a stable straight trajectory, and many exploration goals generated by the frontier explorer were marked `Aborted` or `Failure` within a few seconds. As a result, the robot repeatedly searched for new goals without making reliable exploration progress.

### Post-Run Investigation

Several post-run experiments were conducted to separate software-timing effects from mechanical causes.

First, the robot was tested with the feeder emptied of ping-pong balls. Under this condition, the swaying motion became noticeably less severe. The platform also appeared unstable during teleoperation when the feeder was fully loaded, suggesting that the feeder and payload arrangement introduced a genuine mechanical effect such as vibration, resonance, or a shifted centre of mass.

Second, the same `extrapolation into the future` transform error was reproduced after the final run. In some trials, shutting down the Raspberry Pi, allowing it to cool, and rebooting temporarily reduced the problem, suggesting that system load or thermal state might have amplified timing sensitivity. However, there was no direct evidence of thermal throttling, and the timing issue could still be reproduced during colder post-run tests, so overheating alone was not a sufficient explanation.

Third, the team verified that the issue was not caused by inconsistent ROS clock settings such as `use_sim_time`. The final mitigation was to synchronise the Raspberry Pi and laptop clocks explicitly using `chrony`. After doing so, the transform extrapolation error disappeared in testing and navigation behaviour improved significantly.

### Interpretation

The final-run failure is therefore best understood as the interaction of two separate issues.

The first issue was a software-timing problem in the distributed TF chain. Because odometry was produced on the Raspberry Pi while Cartographer and Nav2 ran on the laptop, the system was sensitive to even modest clock mismatch between devices. The strongest evidence for this interpretation is that explicit clock synchronisation with `chrony` removed the transform extrapolation error.

The second issue was a mechanical stability problem associated with the feeder and payload. The reduction in swaying when the feeder was empty suggests that the loaded payload altered the robot's dynamics. This problem did not directly cause the transform error, but it likely made the platform less tolerant to timing disturbances and degraded path-tracking quality.

Taken together, the evidence suggests that:

- repeated exploration goal aborts were primarily caused by timing inconsistency in the distributed `map -> odom` transform chain
- unstable swaying motion was worsened by feeder and payload dynamics
- the combination of these effects significantly reduced navigation reliability during the final run

### Insights

Two key lessons follow from this investigation.

First, time synchronisation across ROS devices should be treated as a required part of system setup rather than as an optional convenience. In any distributed navigation architecture, clock consistency is essential to reliable transform and odometry handling. Even without Internet access, a local NTP-style synchronisation mechanism should be configured before testing and deployment.

Second, payload mounting should be treated as part of the navigation problem rather than as a purely mechanical afterthought. Future designs should reduce feeder motion, lower the centre of mass where possible, and validate the platform both with and without the full payload installed.

More broadly, the project showed that a distributed autonomous navigation system must be validated not only at the algorithm level, but also at the full system-integration level. Clock synchronisation, TF consistency, payload-induced dynamics, and long-duration runtime stability should all be treated as formal verification items.

## Resonance

During testing, the TurtleBot exhibited pronounced wobble and jitter when the feeder was loaded with nine balls. Teleoperation tests performed with and without the payload suggested that ball motion inside the feeder excited resonant behaviour in the platform. A more rigid feeder design with tighter ball retention, combined with a stronger mechanical attachment to the chassis, would likely reduce this effect.

## Inconsistent Shooting

Uneven cam edges caused one side of the spring mechanism to release before the other, producing angled striker motion and inconsistent shots. Future designs should use cam profiles that are easier to manufacture repeatably, for example by avoiding sharp transitions that are difficult to print accurately.

## Unstable Centre of Gravity

The front-mounted launcher shifted the centre of gravity forward, increasing load on the caster and raising rolling resistance. Because the TurtleBot3 Burger is a differential-drive platform, poor weight distribution also made turning less smooth. A more compact launcher integrated closer to the chassis would improve stability.

## 3D-Printed Part Mismatch

Several printed components required filing or boring during assembly. This was largely caused by manufacturing parts before a complete CAD model of the full launcher assembly had been finalised. Future work should complete the overall model first or include adjustable features that accommodate dimensional uncertainty.

## Unadjustable Parts

Some components, particularly the camera mounts, were delayed because their exact installation positions had not yet been finalised. Adjustable features such as slotted holes would have allowed manufacturing to begin earlier while preserving enough flexibility for final placement during integration.

## Station A Aligner Disabled by Missing Enable Signal

**Observed:** During the graded run, Station A alignment did not start successfully. No annotated frames were published on `/receptacle/annotated`, no offset data was received on `/receptacle/offset`, and the FSM eventually timed out in `ALIGN_AT_A`.

**Root Cause:** Post-run code review showed that `station_a_aligner` processes frames only when its internal `enabled` flag is set to `True`. As a result, all incoming camera frames were discarded before detection, offset publication, or annotated-image output could occur.

```python
class HoughDetectorStationA(Node):

    def __init__(self):
        super().__init__("hough_detector_station_a")

        # ── Linear P-control ──────────────────────────────────────────────
        # Y-axis: camera rotated 90°, so cy drives fwd/bwd.
        self.KP_LINEAR           = 0.0015
        self.MAX_LINEAR_VEL      = 0.08
        self.ALIGN_THRESHOLD     = 15     # pixels on Y-axis
        self.ALIGN_STABLE_FRAMES = 5      # consecutive aligned frames before notifying FSM
        self.align_stable_count  = 0
        self.notified            = False  # service called only once per alignment
        self.enabled             = False  # FSM enables via /aligner_a/set_enabled
```

<p align="center">Code: Station A aligner initialisation</p><br>

```python
    # Image callback
    def image_callback(self, msg):
        if not self.enabled:
            return

        self.frame_count += 1
        if self.frame_count == 1:
            self.get_logger().info("✓ First frame received")

        try:
            frame = cv2.imdecode(np.frombuffer(msg.data, np.uint8), cv2.IMREAD_COLOR)
            if frame is None:
                return
        except Exception as e:
            self.get_logger().error(f"Decode: {e}")
            return
```

<p align="center">Code: Station A aligner image callback gate</p><br>

The aligner depended on a `/aligner_a/set_enabled` service call from the mission controller. However, the submitted FSM did not issue that call when entering `ALIGN_AT_A`, so the aligner remained disabled throughout the run.

**Impact:** Station A alignment never began despite the camera node running normally. The FSM waited for feedback that could never be generated, leading to timeout and mission failure at Station A.

**Improvement:** Add `/aligner_a/set_enabled(True)` on entry to `ALIGN_AT_A`, and use an always-enabled default during early integration testing to make such failures more visible.

## Incorrect Station A Firing Delay Parameters

**Observed:** During the graded run, Station A inter-ball delays were configured as `4.7 s` and `0.7 s` rather than the required `7.0 s` and `3.0 s`.

**Root Cause:** The ROS 2 parameter defaults in the mission controller were not updated after the Week 7 timing specification was released.

**Impact:** Balls 2 and 3 were launched earlier than required, causing scoring penalties even when the launcher itself operated correctly.

**Improvement:** Update parameter defaults to the official values and include a pre-mission checklist for verification of critical timing parameters.

## Docking and Integration [Arnav]

### Docking Pose Accuracy at the Launcher

Observed: The ArUco visual-servo dock (`simple_aruco_dock`) reliably stopped the robot in front of each station marker in isolation, but the final pose was not close enough to the receptacle for the launcher to score consistently. In practice, the robot typically came to rest slightly *too close* to the wall, requiring a small manual nudge before the balls could be fired cleanly.

Root Cause: The docking setpoint (`dock_distance = 0.30 m`, `camera_forward_offset = 0.08 m`) and the post-dock turn-and-shift geometry were tuned against the ArUco marker alone, without closing the loop on the launcher's actual firing pose. The marker is the docking reference, but the *launcher barrel* is what needs to line up with the receptacle opening — and the two were never calibrated together in a single end-to-end test.

Impact: At least one scoring attempt at each station was lost to pose error rather than to detection or control failure.

Improvement / Fix:

- Treat the launcher barrel, not the marker, as the reference frame for the docking setpoint. Re-tune `dock_distance` and the post-shift offset `Δ` against measured launcher-to-receptacle geometry.
- Add a dedicated "launcher pose check" test that scores success on whether a fired ball enters the receptacle, not on whether the dock FSM reaches `DONE`.
- Consider a final fine-alignment stage (either by the aligner node or a secondary visual cue on the receptacle itself) after docking completes, so the docking node can afford a slightly looser final pose.

### Missing End-to-End Dock → Align Integration Test

Observed: Docking, alignment, and launching were each developed and tuned as independent subsystems, and each worked in isolation. However, the *seam* between them — specifically the handover from `DOCK_AT_X` completion into `ALIGN_AT_X` — was never tested end-to-end on the real robot before the graded run. The Station A aligner-enable bug (documented above) is one symptom of this gap; the docking-pose mismatch is another.

Root Cause: Integration testing was treated as a final step rather than a continuous one. Subsystem owners validated their own nodes in isolation (often with hand-placed start poses), and the first time the full `EXPLORE → DOCK → ALIGN → FIRE` chain ran was effectively on the day.

Improvement / Fix:

- Introduce a weekly integration run — even a scripted one on a simplified course — so that interface bugs between docking, alignment, and the launcher surface early.
- Add logging at every FSM transition so that post-run traces clearly show which subsystem failed, rather than only observing mission-level timeout.
- Treat inter-subsystem service calls (e.g. `/aligner_a/set_enabled`, `/aruco_dock/dock_to_a`, `/fire_launcher`) as first-class contract points with their own smoke tests.

### Development Environment and Simulation Fidelity

Observed: One team member developed primarily on macOS using Parallels, and later invested significant time attempting a Docker-based ROS 2 workflow — including Fast DDS network configuration for host ↔ container discovery. Despite the effort, the Docker setup never became usable on the real robot, and much of the work was sunk into debugging DDS, networking, and container plumbing rather than mission logic. In parallel, Gazebo was partially replaced with Foxglove as a visualisation tool, and the Nav2 integration was never meaningfully tested in simulation or on hardware from that environment. Real-robot testing therefore remained dependent on a teammate's Linux laptop being present.

Root Cause: The development environment was chosen for convenience (surviving the course on macOS) rather than for the fastest path to working mission code. Complex setups (Parallels, Docker, DDS tuning, Foxglove-as-Gazebo-replacement) were attempted without a concrete plan for validating each rung of the stack, which made it easy to fall into configuration rabbit holes with no deliverable at the end.

Lesson Learned: Novel or unconventional tooling only pays off when there is both (a) a clear plan for what it needs to achieve and (b) prior experience to bound the debugging cost. In a time-boxed systems project, *getting the job done* on a well-supported stack (native Ubuntu + Gazebo + Nav2) almost always beats investing in a cleaner-feeling alternative. Had we committed to a conventional setup earlier, we would very likely have had the runway to integrate Nav2-based docking, giving us proper obstacle avoidance and a more reliable approach to each station.

Improvement / Fix:

- Standardise the team on a single, well-supported development environment from day one (native Ubuntu 22.04 + ROS 2 Jazzy + Gazebo).
- Require that every contributor be able to run the full simulation stack independently on their own machine — no shared-laptop dependencies.
- Budget exploratory tooling work (Docker, alternative visualisers, macOS bridges) as explicit, time-boxed experiments with clear success criteria, and abandon them quickly if they do not clear the bar.

### Systems Engineering Takeaway

Across all three items above, the common failure mode was the same: we underestimated how much of a systems-engineering project is actually *integration and communication between subsystems*, rather than the subsystems themselves. Individually, docking, alignment, and launching all worked. What cost us on the day was the plumbing between them — service contracts that were not exercised end-to-end, pose frames that were not reconciled across nodes, and a development environment that made integration testing harder than it needed to be. The most valuable investment for a future iteration of this project would be a continuous integration-style workflow that forces every new subsystem change to run against the full mission FSM, rather than in isolation.

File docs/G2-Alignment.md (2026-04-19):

# Receptacle Alignment Subsystem

[Home](../README.md)

## Overview

The receptacle alignment subsystem uses a side-mounted Raspberry Pi Camera V2, rotated 90° counter-clockwise, to detect the circular receptacle opening and align the launcher before firing. Two nodes are used: one for Station A and one for Station B. Both rely on Hough-based geometric alignment, but they differ in how the final firing event is triggered.

Because the camera is physically rotated relative to the robot drive axis, lateral launcher alignment maps to the image `Y` axis rather than the image `X` axis. As a result, all alignment offsets and proportional-control outputs are computed using `cy` rather than `cx`.

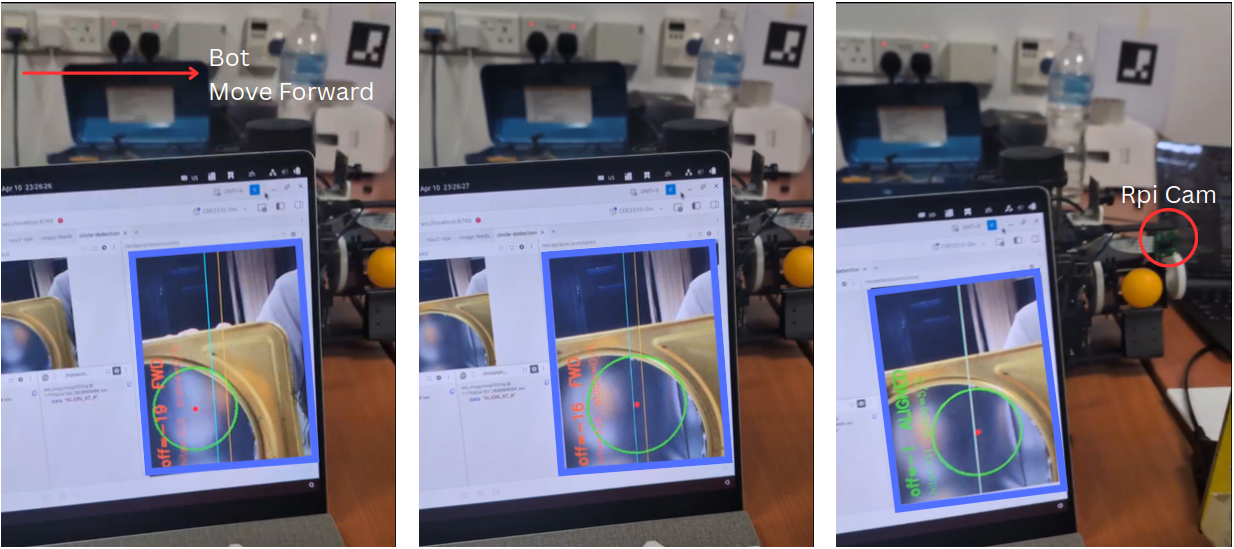
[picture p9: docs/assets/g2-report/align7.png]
align7


<p align="center">Fig: Hough circle detection, Y-axis P-control, and launcher monitoring in Foxglove</p><br>

## Station A: Static Receptacle Alignment

For Station A, the alignment process combines Hough circle detection with a proportional controller on the image `Y` axis.

### Processing Pipeline

For each incoming frame, the node performs the following sequence:

1. Decode the compressed image from `/camera/image_raw/compressed`.
2. Convert the frame to grayscale and apply Gaussian blur.
3. Run `HoughCircles(HOUGH_GRADIENT)` to detect candidate circular openings.
4. Select the largest detected circle as the most likely receptacle.
5. Compute the vertical offset, `offset_y = cy_detected - frame_height / 2`.
6. Smooth the detected center using an exponential moving average.
7. Apply proportional control to generate `linear.x`, clamped to the configured velocity limit.
8. Publish `/cmd_vel` with linear motion only.
9. Count consecutive aligned frames and call `/receptacle/notify_aligned` once the stability threshold is met.

### Tuned Parameters

The following parameters were tuned using physical tests at stand-off distances of approximately 22-38 cm:

| Parameter | Value | Effect |
| --- | --- | --- |
| `Kp` (linear) | `0.0015` | Lower values produce smoother but slower convergence |
| `MAX_LINEAR_VEL` | `0.08 m/s` | Prevents overshoot at short range |
| `ALIGN_THRESHOLD` | `15 px` | Offset band treated as aligned |
| `ALIGN_STABLE_FRAMES` | `5` | Number of consecutive aligned frames required before notifying the FSM |
| `CONFIRM_FRAMES` | `5` | Number of consecutive detections required before a circle is accepted |
| `EMA_ALPHA` | `0.20` | Heavier smoothing reduces jitter |
| `MIN_R / MAX_R` | `80 / 150 px` | Radius window tuned to the operating distance |
| `PARAM2` | `45` | Hough accumulator threshold balancing sensitivity and false positives |

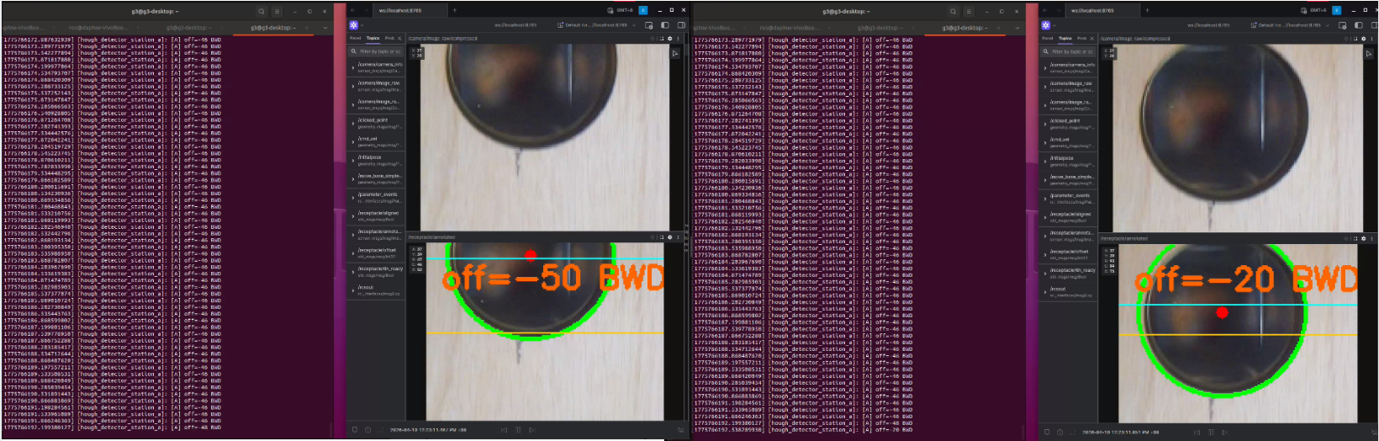
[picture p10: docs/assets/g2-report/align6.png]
align6


<p align="center">Fig: Station A alignment commanding backward motion at approximately 35 cm</p><br>

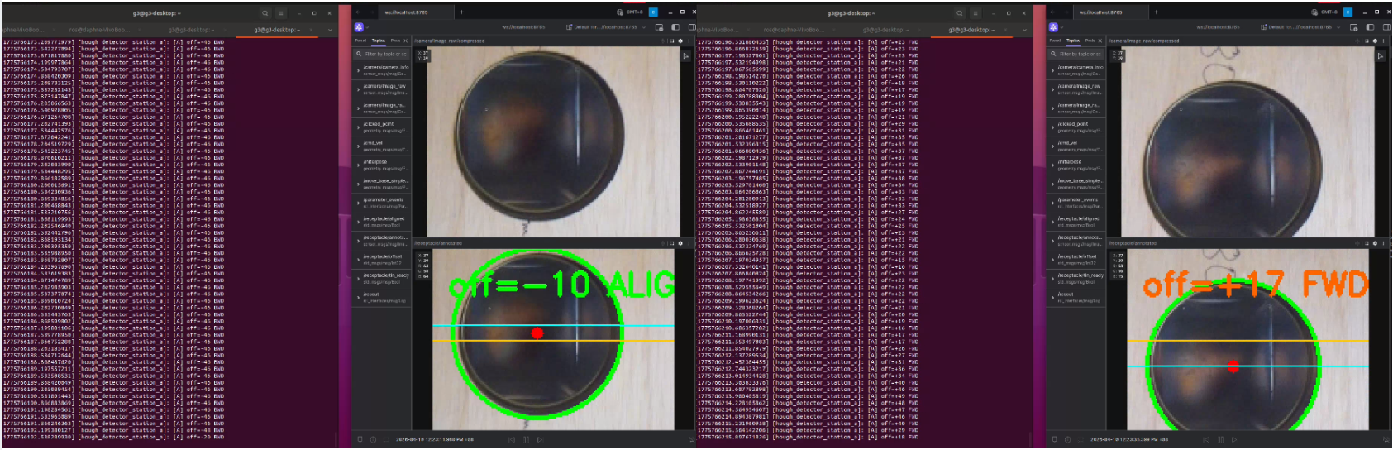
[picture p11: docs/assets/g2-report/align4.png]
align4


<p align="center">Fig: Station A alignment commanding forward motion at approximately 35 cm</p><br>

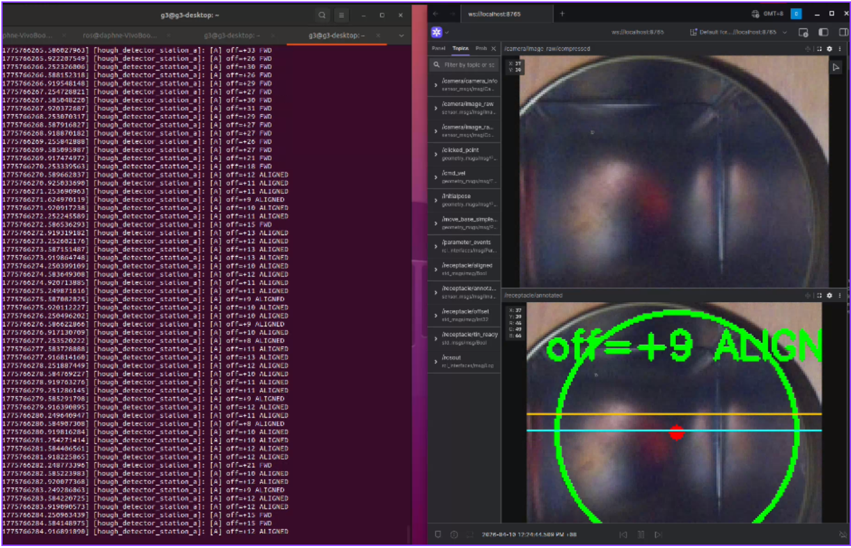
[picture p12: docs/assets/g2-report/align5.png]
align5


<p align="center">Fig: Station A alignment at close range after convergence</p><br>

## Station B: Moving Receptacle Alignment

Station B presents a moving receptacle on a motorised rail, so the subsystem operates in two phases.

### Phase 1: Geometric Alignment

The robot first aligns to the wooden cutout using the same Hough-based `Y`-axis alignment strategy as Station A. Once the alignment condition is satisfied for the required number of consecutive frames, the robot is considered locked and translational motion is set to zero.

### Phase 2: Blue LED Trigger Detection

After geometric alignment, the node waits for the blue LED inside the moving receptacle to become visible through the cutout. LED detection is performed within the Hough-detected circular region of interest using HSV thresholding:

- `H = 100-130`
- `S = 180-255`
- `V = 200-255`

The detection ratio is defined as the number of blue pixels divided by the circle area. A firing event is confirmed only after 30 consecutive positive frames, which suppresses false triggers caused by rail vibration or transient reflections. Each rising edge in LED visibility triggers a `/fire_launcher` call, with `BALLS_TO_FIRE = 1` per event.

### Station B Parameter Adjustments

Most alignment parameters are shared with Station A. The following values were adjusted specifically for Station B:

| Parameter | Value | Remarks |
| --- | --- | --- |
| `EMA_ALPHA` | `0.15` | Stronger smoothing for a noisier visual condition |
| `CONFIRM_FRAMES` | `8` | More frames required before locking onto a valid detection |

### Rationale for HSV Detection

HSV-based detection was selected because brightness-only methods proved unreliable during testing.

1. Reflections inside the receptacle produced brightness values similar to the aligned state even when the receptacle was not properly positioned.
2. Dark objects behind the cutout produced false positives when thresholding was based only on intensity.

By isolating a specific hue range, HSV thresholding was substantially more robust to ambient illumination changes and background variation.

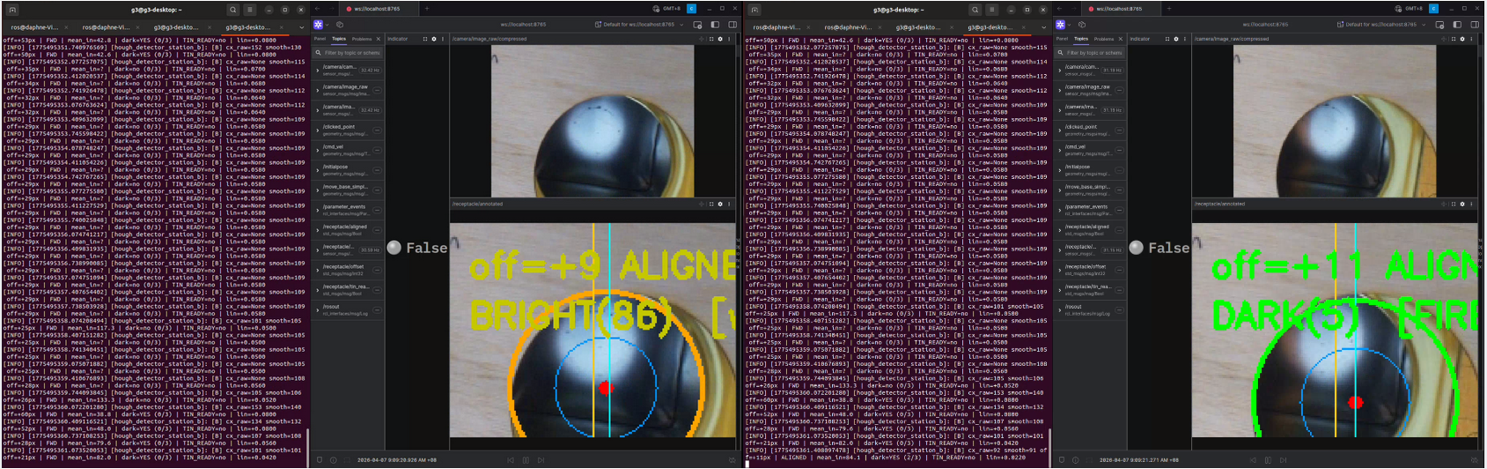
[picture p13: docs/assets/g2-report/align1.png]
align1


<p align="center">Fig: Brightness-threshold failure case for Station B</p><br>

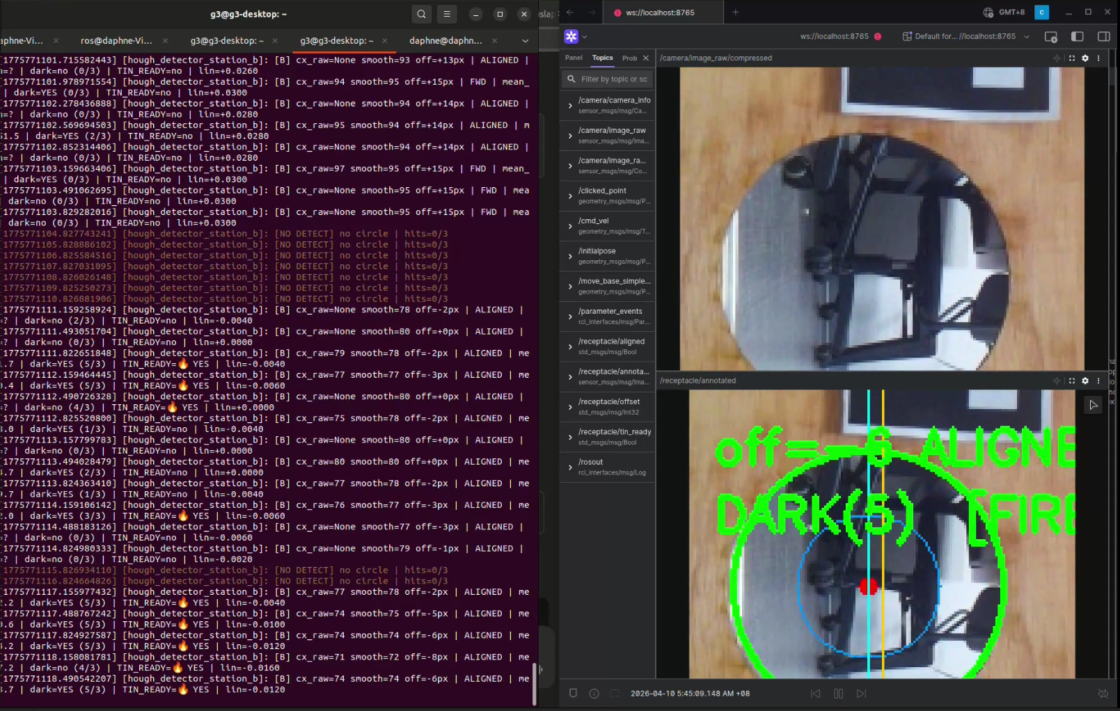
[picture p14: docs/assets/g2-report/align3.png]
align3


<p align="center">Fig: Dark-background false positive case for Station B</p><br>

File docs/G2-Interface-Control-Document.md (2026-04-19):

# Interface Control Document

[Home](../README.md)

## Mechanical Interfaces

The mechanical subsystem combines the TurtleBot3 platform with custom launcher, camera, and support structures. The figures below show the assembled upper and lower layers of the robot, while the table summarises the principal mechanical connections.

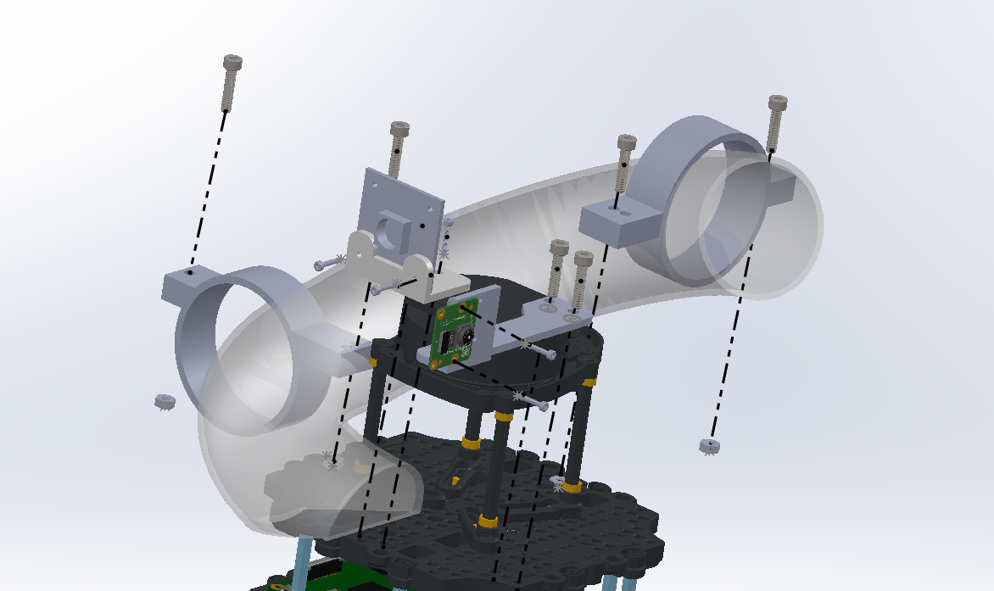
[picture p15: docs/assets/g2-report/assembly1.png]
assembly1


<p align="center">Fig: TurtleBot assembly, Layer 4</p><br>

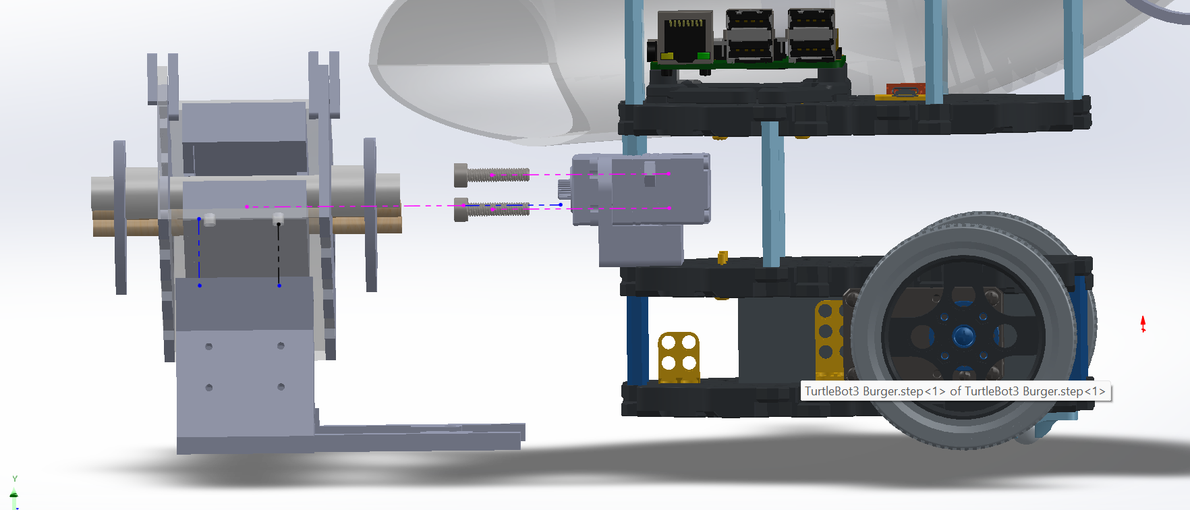
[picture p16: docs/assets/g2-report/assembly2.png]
assembly2


<p align="center">Fig: TurtleBot assembly, Layers 1 and 2</p><br>

| Component 1 | Component 2 | Connection via |
| --- | --- | --- |
| TurtleBot Layer 4 | USB Camera Mount | 2x M2 nuts and bolts |
| TurtleBot Layer 4 | RPi Camera Mount | 2x M4 nuts and bolts |
| TurtleBot Layer 4 | Pipe Mounts | 4x M4 nuts and bolts |
| TurtleBot Layer 2 | UART Servo Mount | 2x M2 nuts and bolts |
| TurtleBot Layer 3 | Servo Encoder | 2x M3 nuts and bolts |
| TurtleBot Layer 1 | Launcher Mount | 4x M4 nuts |
| Launcher Mount | Launcher Housing | 4x M3 nuts |
| Launcher Housing | Launcher Striker | 2x dowels via friction fit |
| Launcher Housing | Launcher-Pipe Pins | Friction fit |
| Launcher-Pipe Pins | Pipe | 2x M2 self-tapping screws |
| Pipe | Pipe Cover | Superglue |
| UART Servo Mount | UART Servo Motor | 4x M3 nuts and bolts |
| UART Servo Motor | Cam | Servo disc fastened with 8x approximately M1.8 screws |
| Cam | Shaft and Secondary Cam | Friction fit |
| USB Camera Mount | USB Camera | 2x M2 nuts, bolts, and washers |
| RPi Camera Mount | RPi Camera | 2x M2 nuts, bolts, and washers |

## Electrical Interfaces

The electrical subsystem connects the launcher actuator, cameras, and LiDAR to the Raspberry Pi and supporting power rails. The table below summarises the primary electrical interfaces.

| Component | Physical Connection | Connector on RPi | Power Source | Voltage | Communication Protocol | Data Rate | Device Node | Purpose |
| --- | --- | --- | --- | --- | --- | --- | --- | --- |
| JOHO UART Servo (Ball Launcher) | USB-to-UART adapter into Raspberry Pi USB-A | USB 2.0 | RPi 5V GPIO (`Pin 2/4`) + GND (`Pin 6`) | 5V DC | UART 8N1 via USB-to-TTL adapter | `115200` bps | `/dev/servo` | Ball launcher motor control in DC mode |
| IMX219 Camera Module | USB cable | USB 3.0 | USB bus power | 5V DC | USB 2.0 UVC | `480 Mbps` | `/dev/video1` | ArUco detection for visual-servo docking |
| RPi Camera (CSI) | 15-pin FFC ribbon cable | CSI camera port | CSI port | 3.3V DC | MIPI CSI-2, 2 lanes | `320x240` BGR888 | `libcamera` | Receptacle alignment using Hough circle detection |
| LDS-02 LiDAR | 4-pin JST to USB2LDS to USB-A | USB 2.0 | USB bus power | 5V DC | UART 8N1 over USB (CDC-ACM) | `230400` bps | `/dev/ttyUSB0` | 2D scan input for SLAM and navigation |

## Software Interfaces

### Mission Controller ↔ Frontier Explorer

The frontier explorer is a standalone node built on `BasicNavigator` from `nav2_simple_commander`. It manages its own navigation goal lifecycle internally, while the mission controller enables or disables exploration as required by the high-level mission sequence.

| Interface | Type | Nodes / Direction | Trigger | Data Type | Description |
| --- | --- | --- | --- | --- | --- |
| `/exploration/set_enabled` | Service | `mission_controller → frontier_explorer` | `INIT → EXPLORE`, `EXPLORE → DOCK`, station completion | `SetBool` | Enables or disables the planning loop. Enabling clears cluster blacklists and failure counters; disabling cancels the active Nav2 goal and halts exploration. |
| `/exploration_complete` | Topic | `frontier_explorer → mission_controller` | No valid frontiers for repeated planning cycles, or encapsulation completion | `Bool` | Signals that exploration is complete. Published with transient-local QoS. |
| `/exploration/frontiers` | Topic | `frontier_explorer → RViz` | Every planning tick | `MarkerArray` | Visualisation of current frontier cells, blacklisted regions, and active goal. |
| `/exploration/current_goal` | Topic | `frontier_explorer → RViz` | On goal dispatch | `PoseStamped` | Visualisation of the active exploration goal. |
| `/navigate_to_pose` | Action | `frontier_explorer → Nav2 BT Navigator` | Best frontier selected | `NavigateToPose` | Executes the active exploration goal with timeout and retry handling. |
| `/compute_path_to_pose` | Action | `frontier_explorer → Nav2 Planner Server` | Candidate validation | `ComputePathToPose` | Verifies path feasibility before goal commitment. |

### Mission Controller ↔ Visual Servo

`simple_aruco_dock` operates in two modes: passive scanning during exploration and active docking during the final approach to a selected station.

| Interface | Type | Nodes / Direction | Trigger | Data Type | Description |
| --- | --- | --- | --- | --- | --- |
| `/station_a_pose` | Topic | `simple_aruco_dock → mission_controller` | Station A marker detected during passive scan | `PoseStamped` | Publishes the detected station pose so the FSM can mark Station A as found. |
| `/station_b_pose` | Topic | `simple_aruco_dock → mission_controller` | Station B marker detected during passive scan | `PoseStamped` | Same as above for Station B. |
| `/aruco_dock/dock_to_a` | Service | `mission_controller → simple_aruco_dock` | Entering `DOCK_AT_A` | `Trigger` | Switches the docking node into active approach mode for marker 42. |
| `/aruco_dock/dock_to_b` | Service | `mission_controller → simple_aruco_dock` | Entering `DOCK_AT_B` | `Trigger` | Switches the docking node into active approach mode for marker 67. |
| `/cmd_vel` | Topic | `simple_aruco_dock → motor driver` | Every camera frame during active docking | `TwistStamped` | PI-control output for final approach. |
| `/aruco_dock/done` | Topic | `simple_aruco_dock → mission_controller` | Docking criteria satisfied | `Bool` | Signals completion of the docking manoeuvre. |
| `/aruco_dock/scan` | Service | `mission_controller → simple_aruco_dock` | Leaving docking mode | `Trigger` | Returns the docking node to passive scanning and resets internal reporting flags. |
| `/aruco_dock/marker_visible` | Topic | `simple_aruco_dock → mission_controller` | Every camera frame | `Bool` | Indicates whether a known marker is visible in the current image. |
| `/aruco_dock/marker_distance` | Topic | `simple_aruco_dock → mission_controller` | Every detected frame | `Float32` | Publishes the raw `solvePnP` distance estimate to the target marker. |

### Mission Controller ↔ Station A Aligner

`station_a_aligner` subscribes to the compressed CSI camera stream, performs Hough-based circle detection, and commands linear alignment motion while the robot is in `ALIGN_AT_A`.

| Interface | Type | Nodes / Direction | Trigger | Data Type | Description |
| --- | --- | --- | --- | --- | --- |
| `/aligner_a/set_enabled` | Service | `mission_controller → station_a_aligner` | Entering or leaving `ALIGN_AT_A` | `SetBool` | Enables or disables image processing and command output. |
| `/receptacle/offset` | Topic | `station_a_aligner → mission_controller` | Every camera frame | `Int32` | Publishes `Y`-axis pixel offset; `9999` indicates no circle detected. |
| `/receptacle/tin_ready` | Topic | `station_a_aligner → mission_controller` | Every camera frame | `Bool` | Continuous alignment status signal. |
| `/receptacle/notify_aligned` | Service | `station_a_aligner → mission_controller` | Required number of consecutive aligned frames | `Trigger` | One-shot alignment notification to the FSM. |
| `/cmd_vel` | Topic | `station_a_aligner → motor driver` | Every enabled frame | `Twist` | Linear-only alignment command. |
| `/receptacle/annotated` | Topic | `station_a_aligner → Foxglove` | Every camera frame | `Image` | Annotated debug view with Hough detections and alignment overlay. |
| `/camera/image_raw/compressed` | Topic | `csi_cam → station_a_aligner` | Camera publish rate | `CompressedImage` | Input image stream from the rotated CSI camera. |

### Mission Controller ↔ Station B Aligner

`station_b_aligner` handles both geometric alignment and autonomous firing for the moving receptacle at Station B.

| Interface | Type | Nodes / Direction | Trigger | Data Type | Description |
| --- | --- | --- | --- | --- | --- |
| `/receptacle/b_done` | Topic | `station_b_aligner → mission_controller` | All required shots completed | `Bool` | Signals completion of Station B firing. |
| `/fire_launcher` | Service | `station_b_aligner → ball_launcher_node` | Blue LED rising edge detected | `Trigger` | Direct firing call from the Station B aligner. |
| `/cmd_vel` | Topic | `station_b_aligner → motor driver` | Every camera frame during geometric alignment | `Twist` | Linear alignment command; held at zero during the LED-wait phase. |
| `/receptacle/offset` | Topic | `station_b_aligner → mission_controller` | Every camera frame | `Int32` | Publishes the same offset contract used by Station A. |
| `/receptacle/tin_ready` | Topic | `station_b_aligner → mission_controller` | LED-detection phase | `Bool` | Indicates that the blue LED is currently detected within the target region. |
| `/receptacle/annotated` | Topic | `station_b_aligner → Foxglove` | Every camera frame | `Image` | Debug overlay showing phase, LED detection state, and ball count. |
| `/camera/image_raw/compressed` | Topic | `csi_cam → station_b_aligner` | Camera publish rate | `CompressedImage` | Shared input stream from the CSI camera. |

### Mission Controller ↔ Ball Launcher

The launcher node runs on the Raspberry Pi and exposes a simple service-and-status interface for firing control.

| Interface | Type | Nodes / Direction | Trigger | Data Type | Description |
| --- | --- | --- | --- | --- | --- |
| `/fire_launcher` | Service | `mission_controller → ball_launcher_node` | Station A firing sequence | `Trigger` | Starts a timed launcher cycle if the launcher is idle and available. |
| `/launcher_status` | Topic | `ball_launcher_node → mission_controller` | Continuous timer | `String` | Reports `idle`, `firing`, `complete`, or `error`. |
| `/stop_launcher` | Service | `ball_launcher_node` | Manual emergency stop | `Trigger` | Interrupts the firing thread and returns the launcher to a safe idle state. |

## Nodes Launch Location

The final deployment distributed nodes between the Raspberry Pi and the operator laptop as follows:

| Platform | Nodes | Peripherals |
| --- | --- | --- |
| Raspberry Pi | `turtlebot3_bringup` | LDS-02 LiDAR, Dynamixel motors |
| Raspberry Pi | `usb_cam` | IMX219 USB camera |
| Raspberry Pi | `csi_cam` | RPi CSI camera |
| Raspberry Pi | `ball_launcher_node` | JOHO servo in launcher mechanism |
| Laptop (Docker) | Cartographer, Nav2, `frontier_explorer`, `post_exploration_traverser`, `simple_aruco_dock`, `station_a_aligner`, `station_b_aligner`, `mission_controller`, `foxglove_bridge` | None |

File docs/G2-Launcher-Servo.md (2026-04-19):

# Launcher and Servo Subsystem

[Home](../README.md)

The launcher subsystem uses a JOHO 25 kg-cm UART bus servo operated in DC motor mode and controlled by `ball_launcher_node.py` in the `g3_ball_launcher` package. Communication is performed over a USB-to-UART adapter at `115200` bps through a bundled Python SDK (`uart_sdk/`) that implements the servo packet protocol.

On startup, the node places the servo in DC mode (`MOTOR_MODE_DC = 0x00`), rotates it slowly to recover a known initial position (`CURRENT_POSITION = 4000`), and then returns to the `idle` state. When `/fire_launcher` is called, the node starts a daemon thread that issues `dc_rotate(CW, 100%)` for `2.2` seconds before calling `dc_stop()`. The launcher status progresses through `idle → firing → complete → idle`, with the `complete` state held briefly so that the mission controller can observe the transition on `/launcher_status`.

The implementation includes two layers of protection for runtime reliability. A status lock (`_lock`) prevents concurrent state corruption, while a separate UART lock (`_serial_lock`) protects access to the serial interface. A `threading.Event` is used to signal stop requests and support safe interruption of an active firing cycle.

cad1

cad2

<p align="center">Fig: Mechanical subsystem drawings</p><br>

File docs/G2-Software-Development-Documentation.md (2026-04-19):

# Software Development Documentation

[Home](../README.md)

## ROS 2 Packages and Nodes

The final software stack was divided into modular ROS 2 packages so that each subsystem could be developed, tested, and integrated independently.

| Subsystem | Package(s) | Nodes | Responsibility |
| --- | --- | --- | --- |
| Mission Control | `g3_mission_control` | `mission_controller` | High-level FSM orchestration across exploration, docking, alignment, and firing |
| Visual Servo | `g3_visual_servo` | `simple_aruco_dock` | ArUco detection, station reporting, and short-range docking control |
| Exploration | `g3g_frontier_exploration` | `frontier_explorer` | Frontier selection, goal dispatch, and exploration completion logic |
| Exploration | `g3g_frontier_exploration` | `post_exploration_traverser` | Residual free-space traversal after frontier exhaustion |
| Receptacle Alignment | `g3_aligner` | `station_a_aligner` | Hough-based alignment for the static receptacle at Station A |
| Receptacle Alignment | `g3_aligner` | `station_b_aligner` | Hough alignment plus blue-LED-triggered firing for Station B |
| Ball Launcher | `g3_ball_launcher` | `ball_launcher_node` | UART servo control for timed firing and stop/status reporting |
| Navigation | `g3nav2` | Cartographer, RViz, Nav2 lifecycle nodes | Real-hardware launch files, navigation configuration, and SLAM integration |
| Simulation | `g3gzsim` | Gazebo and ROS-GZ support nodes | Simulation worlds, robot models, and sim-specific launch/configuration files |

## Development Environment, Networking Strategy, and Debugging Workflow

This section summarises the main tools, workflows, and engineering conventions adopted during development. These choices were driven not only by convenience, but also by the realities of building a distributed ROS 2 system across a TurtleBot Raspberry Pi and an operator laptop.

### Networking and System Configuration

Early in the project, mobile-phone hotspots were suggested as the default networking approach. In practice, this proved unsuitable for sustained development and debugging. The arrangement was fragile, required the phone to remain physically present and powered, and introduced extra latency and bandwidth limitations. It also made network reconfiguration cumbersome because the Raspberry Pi often had to be reconnected to a monitor and keyboard for manual changes.

To improve this setup, several changes were made. First, Ubuntu Desktop was installed on the Raspberry Pi instead of Ubuntu Server. This simplified network configuration, especially when connecting to the campus `NUS_STU` Wi-Fi network with WPA2/PEAP authentication. Second, the Raspberry Pi was linked to a dedicated Tailscale account so that the robot remained remotely reachable even when it was not on the same local network as the operator laptop.

Because ROS 2 communication over Tailscale alone was not fully satisfactory, Husarnet combined with `ROS_DISCOVERY_SERVER` was also evaluated as a fallback remote-debugging option. Although this worked for lightweight ROS traffic, video latency and bandwidth limitations made it unsuitable as the primary workflow.

The final preferred setup was to connect the Raspberry Pi directly to the operator laptop's Wi-Fi hotspot while providing the laptop with separate Internet access through Ethernet when needed. In this configuration, the Raspberry Pi could still reach Tailscale through `NUS_STU` at boot, after which `nmcli` was used to switch it onto the laptop hotspot for lower-latency ROS communication. This became the final operational network topology used during deployment.

### ROS 2 Version and Development Platform

During experimentation with remote ROS workflows, references suggested that the `ROS_DISCOVERY_SERVER` approach was not ideal for ROS 2 Humble in this use case. Subsequent testing also showed that ROS 2 Jazzy behaved more reliably for Gazebo installation and simulation. For these reasons, the software development environment was standardised on ROS 2 Jazzy.

To support development across Ubuntu 22.04 and Windows WSL hosts, the team adopted a Docker-based workflow for development and simulation. This reduced onboarding friction and improved reproducibility by avoiding manual recreation of dependencies on each host system. For deployment on the robot, however, the software stack was run natively on Ubuntu 24.04 for better compatibility and operational simplicity.

### Integration and Debugging Workflow

As the project matured, the number of interacting subsystems increased significantly. Running the entire stack through a single long launch command became increasingly inconvenient because it made it difficult to isolate logs, restart individual components, or inspect failures in real time.

To address this, the team created a set of `tmux` scripts that automatically opened a 2x2 panel layout and prefilled each pane with the appropriate startup commands for selected subsystems. Grouping panes by subsystem rather than by machine or launch stage made the setup easier to understand during integration and allowed multiple team members to inspect different parts of the system simultaneously.

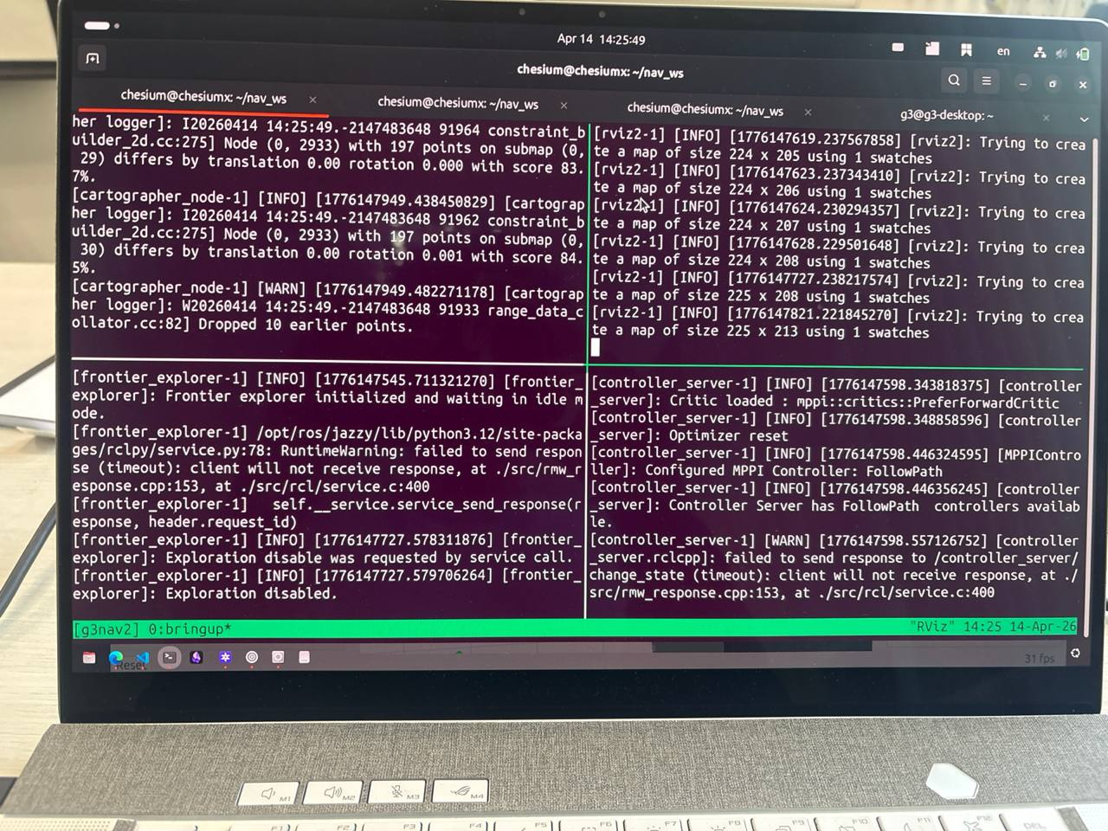
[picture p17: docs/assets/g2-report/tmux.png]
tmux


<p align="center">Fig: One of the `tmux` launch layouts used during integration and debugging</p><br>

### Visualisation and Runtime Monitoring

In addition to RViz, Foxglove was adopted as a dashboard for monitoring camera streams and other ROS 2 topics. Its tab-based layout made it straightforward to maintain separate workspaces for navigation, perception, and system-level monitoring. Compared with RViz, Foxglove was especially effective for building multi-panel views quickly and for inspecting fields within structured ROS messages during subsystem debugging.

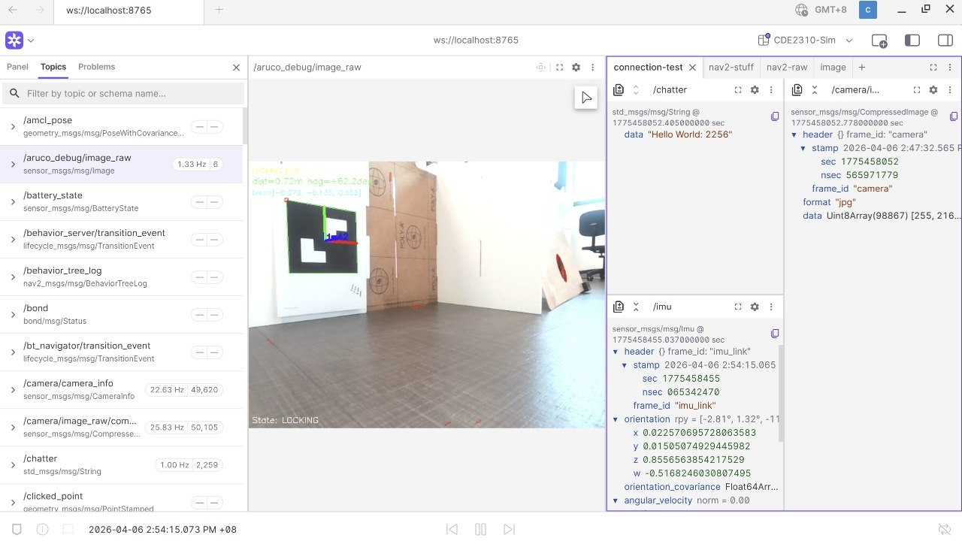
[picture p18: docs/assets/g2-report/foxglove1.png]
foxglove1


<p align="center">Fig: Foxglove dashboard used during runtime monitoring</p><br>

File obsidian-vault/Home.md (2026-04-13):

# CDE2310 Robot Project - Knowledge Base

> **NUS CDE2310** - Autonomous warehouse robot that explores, finds ArUco-marked stations, navigates to them, aligns with receptacles, and fires balls.
> 
> Platform: TurtleBot3 Burger | ROS 2 Jazzy | Gazebo Harmonic | Nav2

---

## Quick Links

| What | Where |
|---|---|
| [[Architecture Overview]] | System design, data flow, node graph |
| [[ROS2 Topic and Service Map]] | Every topic, service, and action |
| [[State Machine Reference]] | FSM diagrams for all controllers |
| [[How to Run Everything]] | Build, sim, hardware, teleop |
| [[Package Index]] | All 7 packages explained |

---

## Package Map

```
src/
├── g3_mission_control/    → [[g3_mission_control]]  FSM orchestrator
├── g3_visual_servo/       → [[g3_visual_servo]]      ArUco detection + docking
├── g3g_frontier_exploration/ → [[g3g_frontier_exploration]]  Autonomous map exploration
├── g3_ball_launcher/      → [[g3_ball_launcher]]     UART servo motor control
├── g3gzsim/               → [[g3gzsim]]              Gazebo simulation + launch files
├── g3nav2/                → [[g3nav2]]               Nav2 config for real hardware
└── g3_receptacle_aligner/ → [[g3_receptacle_aligner]] Hough circle alignment
```

---

## The Mission (What This Robot Does)

```mermaid
graph LR
    A[Start] --> B[Explore Environment]
    B --> C{Found Station?}
    C -->|Station A marker 42| D[Navigate to A]
    C -->|Station B marker 67| E[Navigate to B]
    D --> F[Align with Receptacle]
    E --> G[Align with Receptacle]
    F --> H[Fire 3 Balls<br/>with timing delays]
    G --> I[Fire 3 Balls<br/>no delays]
    H --> J{Other station<br/>found?}
    I --> J
    J -->|Yes| K[Navigate to other station]
    J -->|No| B
    K --> L[Align + Fire]
    L --> M[Mission Complete]
```

### Station A (Static receptacle)
- ArUco marker ID: **42** (4x4_100 dictionary)
- Ball 1 -> **7s wait** -> Ball 2 -> **3s wait** -> Ball 3
- Alignment: Hough circle detection, linear P-control

### Station B (Moving receptacle)  
- ArUco marker ID: **67** (4x4_100 dictionary)
- Ball 1 -> Ball 2 -> Ball 3 (no delays)

---

## Key Concepts

- [[What is a Finite State Machine]] - How the mission controller works
- [[ArUco Markers Explained]] - How visual detection works
- [[Frontier Exploration Explained]] - How the robot explores unknown space
- [[Nav2 Basics]] - Navigation stack overview
- [[PI Control for Docking]] - How the closed-loop servo control works

---

## Current Status & Active Work

- Transitioning docking from legacy `aruco_dock_node.py` to Nav2's `opennav_docking` framework
- New `aruco_dock_pose_publisher.py` publishes to `/detected_dock_pose` for Nav2 docking server
- Simulation testbed: `nav2_docking_sim_test.launch.py`

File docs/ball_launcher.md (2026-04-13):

# g3_ball_launcher

ROS 2 driver node that receives fire requests from the mission controller and drives a UART bus servo in DC motor mode to launch balls.

## Package Structure

```
g3_ball_launcher/
├── g3_ball_launcher/
│   ├── ball_launcher_node.py   # Main ROS 2 node
│   └── uart_sdk/               # Bundled UART servo SDK (JOHO)
│       ├── uart_servo.py       # UartServoManager class
│       ├── packet.py           # Packet framing/parsing
│       ├── packet_buffer.py    # Serial receive buffer
│       └── data_table.py       # Register addresses and constants
├── package.xml
└── setup.py
```

## Node: `ball_launcher_node`

### Services

| Service | Type | Description |
|---|---|---|
| `/fire_launcher` | `std_srvs/srv/Trigger` | Request one launcher shot |
| `/stop_launcher` | `std_srvs/srv/Trigger` | Stop the motor immediately |

### Topics

| Topic | Type | Direction | Description |
|---|---|---|---|
| `/launcher_status` | `std_msgs/String` | Publishes | Reports current launcher state at 10 Hz |

### Launcher Status Values

| Value | Meaning |
|---|---|
| `idle` | Ready to accept a fire command |
| `firing` | Motor spinning, ball being launched |
| `complete` | Shot done, notifying mission controller |
| `error` | Serial link unavailable or command failed |

### Hardware Config

Defined as constants at the top of `ball_launcher_node.py`:

| Constant | Default | Description |
|---|---|---|
| `SERVO_PORT` | `/dev/ttyUSB0` | USB serial port the servo is connected to |
| `SERVO_BAUD` | `115200` | Baud rate (must match servo configuration) |
| `SERVO_ID` | `1` | Servo ID on the UART bus |
| `FIRE_DURATION` | `2.2` | Seconds to spin motor per ball |

## Fire Sequence

```
Mission controller calls /fire_launcher
    ↓
fire service callback accepts request
    ↓
status = 'firing'  (blocks further fire commands)
    ↓
Background thread starts:
    dc_rotate(CW, PWM=100)
    sleep(FIRE_DURATION)
    dc_stop()
    ↓
status = 'complete'  (mission controller increments ball count)
    ↓
sleep(0.1s)
    ↓
status = 'idle'  (ready for next ball)
```

## Dependencies

- `rclpy`, `std_msgs` — ROS 2
- `std_srvs` — fire/stop service interfaces
- `python3-serial` (`pyserial`) — UART serial communication

### Installing pyserial

```bash
# via apt (preferred)
sudo apt install python3-serial

# or via pip inside dev container
pip install pyserial --break-system-packages
```

## Building

```bash
cd ~/nav_ws
colcon build --packages-select g3_ball_launcher
source install/setup.bash
```

## Running

```bash
ros2 run g3_ball_launcher ball_launcher_node
```

## Testing

In separate terminals:

```bash
# Terminal 1 — run the node
ros2 run g3_ball_launcher ball_launcher_node

# Terminal 2 — monitor status
ros2 topic echo /launcher_status

# Terminal 3 — trigger a shot
ros2 service call /fire_launcher std_srvs/srv/Trigger "{}" 

# Terminal 4 — stop the launcher
ros2 service call /stop_launcher std_srvs/srv/Trigger "{}"
```

Expected output on `/launcher_status`: `idle` → `firing` → `complete` → `idle`

## Interface with Mission Controller

The mission controller (`g3_mission_control`) checks both conditions before firing:
```python
launcher_ready == True AND launcher_status == 'idle'
```

- `launcher_ready` is set `False` when a fire request is accepted, and `True` when `complete` is received
- The node **must** return to `idle` after `complete` or the mission controller will not fire the next ball

Inter-ball delays (e.g. 7s after ball 1 at Station A) are handled entirely by the mission controller — this node does not need to implement them.

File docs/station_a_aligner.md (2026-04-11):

# g3_aligner — Station A

ROS 2 node that detects the tin receptacle circle via Hough circle detection and aligns the bot to it using Y-axis P-control. Notifies the mission controller FSM once stable alignment is achieved; firing is handled entirely by the FSM.

## Package Structure

```
g3_aligner/
├── g3_aligner/
│   ├── station_a_aligner.py   # Station A alignment node
│   └── station_b_aligner.py   # Station B alignment node
├── package.xml
└── setup.py
```

## Node: `station_a_aligner`

### Camera Orientation

The RPi camera is mounted **rotated 90° left** on the bot. As a result:

- Lateral alignment uses the **Y-axis** (`cy`) of the detected circle instead of `cx`.
- `offset_y > 0` (circle below frame centre) → bot drives **backward**
- `offset_y < 0` (circle above frame centre) → bot drives **forward**

### Topics

| Topic | Type | Direction | Description |
|---|---|---|---|
| `/camera/image_raw/compressed` | `sensor_msgs/CompressedImage` | Subscribes | Raw camera feed from RPi |
| `/receptacle/offset` | `std_msgs/Int32` | Publishes | Y-axis pixel offset from frame centre; `9999` when no circle detected |
| `/receptacle/tin_ready` | `std_msgs/Bool` | Publishes | `True` when aligned within threshold |
| `/receptacle/annotated` | `sensor_msgs/Image` | Publishes | Debug feed with alignment lines overlaid |
| `/cmd_vel` | `geometry_msgs/Twist` | Publishes | Linear X only (fwd/bwd); angular Z always `0` |

### Services Called

| Service | Type | Description |
|---|---|---|
| `/receptacle/notify_aligned` | `std_srvs/srv/Trigger` | Called once when stable alignment is reached; triggers FSM transition to `FIRE_AT_A` |

### Tuning Parameters

Defined as instance constants in `__init__`:

| Parameter | Default | Description |
|---|---|---|
| `KP_LINEAR` | `0.002` | P-gain for Y-axis linear velocity |
| `MAX_LINEAR_VEL` | `0.08` m/s | Clamp on commanded linear speed |
| `ALIGN_THRESHOLD` | `15` px | Pixel tolerance for "aligned" on Y-axis |
| `ALIGN_STABLE_FRAMES` | `5` | Consecutive aligned frames before notifying FSM |
| `CONFIRM_FRAMES` | `4` | Consecutive detection hits before circle is considered confirmed |
| `EMA_ALPHA` | `0.35` | Exponential moving average weight for `cy` smoothing |
| `DP` | `1.2` | Hough accumulator resolution ratio |
| `MIN_DIST` | `100` px | Minimum distance between detected circle centres |
| `PARAM1` | `50` | Canny high threshold for Hough |
| `PARAM2` | `25` | Accumulator threshold for circle detection |
| `MIN_R` / `MAX_R` | `55` / `75` px | Radius range, tuned for 22–38 cm distance |

## Alignment Flow

```
Camera frame received
    ↓
Hough circle detection (GaussianBlur → HoughCircles)
    ↓
Temporal filter: require CONFIRM_FRAMES consecutive hits
    ↓
EMA smoother on cy (weight = EMA_ALPHA)
    ↓
offset_y = cy_smooth - frame_centre_y
    ↓
P-control: linear_vel = clamp(KP_LINEAR * offset_y, ±MAX_LINEAR_VEL)
    publish /cmd_vel (linear.x = 0 if aligned, else linear_vel)
    ↓
If |offset_y| < ALIGN_THRESHOLD for ALIGN_STABLE_FRAMES frames
    AND service not yet called this alignment:
        call /receptacle/notify_aligned  ←── FSM transitions to FIRE_AT_A
    ↓
FSM calls /fire_launcher (handled by g3_ball_launcher)
```

If the circle is lost mid-alignment:
- `consecutive_hits` decrements each frame; `confirmed` clears at zero
- EMA state is reset — no stale position reuse
- `notified` resets on misalignment so re-alignment can re-notify

## Dependencies

- `rclpy`, `sensor_msgs`, `std_msgs`, `geometry_msgs`, `std_srvs` — ROS 2
- `cv_bridge` — ROS ↔ OpenCV image conversion
- `opencv-python` (`cv2`) — Hough circle detection
- `numpy` — image array processing

## Building

```bash
cd ~/nav_ws
colcon build --packages-select g3_aligner
source install/setup.bash
```

## Running

```bash
ros2 run g3_aligner station_a_aligner
```

## Testing

```bash
# Terminal 1 — run the node
ros2 run g3_aligner station_a_aligner

# Terminal 2 — monitor Y-axis offset
ros2 topic echo /receptacle/offset

# Terminal 3 — monitor alignment gate
ros2 topic echo /receptacle/tin_ready

# Terminal 4 — watch debug feed (requires rqt or image_view)
ros2 run image_view image_view --ros-args -r image:=/receptacle/annotated
```

Expected `/receptacle/offset` approaches `0` as the bot moves, then `/receptacle/tin_ready` publishes `True` and the FSM is notified via `/receptacle/notify_aligned`.

## Interface with Mission Controller

The FSM (`g3_mission_control`) exposes `/receptacle/notify_aligned` as a service server. On receipt:

- FSM transitions from `ALIGN_AT_A` → `FIRE_AT_A`
- FSM calls `/fire_launcher` on `g3_ball_launcher`

The aligner continues publishing `/receptacle/tin_ready` for FSM monitoring throughout.
If the notification call finds the service unavailable or returns a rejection, `notified` is reset and the call is retried on the next stable frame.

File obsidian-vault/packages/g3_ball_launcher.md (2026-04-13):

# g3_ball_launcher

> **Type:** `ament_python` package
> **Purpose:** Controls the physical ball-launching servo motor via UART serial

## Files

| File | Lines | Purpose |
|---|---|---|
| `ball_launcher_node.py` | ~260 | ROS2 node wrapping servo control |
| `uart_sdk/uart_servo.py` | | UART servo communication manager |
| `uart_sdk/packet.py` | | Serial packet encoding/decoding |
| `uart_sdk/data_table.py` | | Servo register definitions + constants |
| `uart_sdk/packet_buffer.py` | | Serial buffer management |

## How It Works

### Hardware
- **Servo**: Connected via USB-to-UART adapter (`/dev/ttyUSB0` at 115200 baud)
- **Motor mode**: DC mode (continuous rotation, not position servo)
- **Shooting**: Spin motor CW at 100% PWM for 2.2 seconds per ball

### ROS2 Interface

| Interface | Type | Purpose |
|---|---|---|
| `/launcher_status` (pub) | String | Broadcasts state at 10Hz: "idle", "firing", "complete", "error" |
| `/fire_launcher` (service) | Trigger | Mission controller calls this to fire one ball |
| `/stop_launcher` (service) | Trigger | Emergency stop |

### Firing Sequence

```mermaid
sequenceDiagram
    participant MC as Mission Controller
    participant BL as Ball Launcher
    participant Servo as UART Servo
    
    MC->>BL: /fire_launcher (Trigger)
    BL->>BL: Check status == "idle"
    BL-->>MC: success=true, "Fire request accepted"
    BL->>BL: status = "firing"
    BL->>Servo: dc_rotate(CW, 100%)
    Note over BL: Wait 2.2 seconds (background thread)
    BL->>Servo: dc_stop()
    BL->>BL: status = "complete"
    BL->>MC: /launcher_status = "complete"
    Note over BL: 0.1s pause for MC to read
    BL->>BL: status = "idle"
```

### Thread Safety
- `_lock`: Protects `self.status` from concurrent read/write
- `_serial_lock`: Protects UART communications
- `_stop_requested`: `threading.Event` for safe interruption
- Fire runs in a **daemon thread** so it doesn't block ROS callbacks

### Error Recovery
- If serial connection fails, status goes to "error"
- A 1Hz timer (`_ensure_servo_connection`) retries connection
- If USB cable is replugged, node auto-reconnects

### Parameters

| Parameter | Default | Purpose |
|---|---|---|
| `servo_port` | `/dev/ttyUSB0` | USB serial port |
| `servo_baud` | 115200 | Baud rate |
| `servo_id` | 1 | Servo bus ID |
| `fire_duration` | 2.2 | Seconds to spin motor per shot |

### UART SDK

The `uart_sdk/` subdirectory is a bundled Python driver for the servo:
- `data_table.py` defines motor modes (`MOTOR_MODE_DC`, `MOTOR_MODE_SERVO`) and directions (`DC_DIR_CW`)
- `uart_servo.py` provides `UartServoManager` with methods like `dc_rotate()`, `dc_stop()`, `torque_enable()`
- Communication uses custom packet protocol over serial

---

**See also:** [[g3_mission_control]] (the node that calls `/fire_launcher`)

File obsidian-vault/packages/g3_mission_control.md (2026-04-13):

# g3_mission_control

> **Type:** `ament_python` package
> **Purpose:** High-level mission orchestration via Finite State Machines

## Files

| File | Lines | Purpose |
|---|---|---|
| `mission_controller.py` | ~700 | Full competition FSM (by Daphne) |
| `simple_mission_fsm.py` | ~225 | Minimal teaching FSM |
| `mission_controller_stub.py` | ? | Placeholder/stub |
| `mission_controller_2.0.py` | ? | Older version |

## Entry Points (setup.py)

```python
'mission_controller = g3_mission_control.mission_controller:main'
'simple_mission_fsm = g3_mission_control.simple_mission_fsm:main'
```

## mission_controller.py - Deep Dive

### What It Does
Runs the entire competition mission:
1. Waits for Nav2
2. Monitors for station detections during exploration
3. Interrupts exploration to navigate to found stations
4. Aligns with receptacle using Hough circle P-controller
5. Fires 3 balls with station-specific timing
6. Moves to next station or resumes exploration

### Key Design Decisions

**Strategy: "Deliver As Found"**
- When a station is detected, immediately interrupt exploration and navigate there
- Don't wait for both stations to be found
- This minimizes total mission time

**Alignment is split across two nodes:**
- `offset_callback()` runs at camera rate (~30Hz) for smooth P-control
- `handle_alignment()` runs at 10Hz FSM tick for state management
- This separation avoids jerky movement

**Firing uses callbacks, not polling:**
- `launcher_callback("complete")` triggers delay timer
- `handle_firing()` manages the sequence
- Fire-and-forget service calls so FSM tick never blocks

### Parameters

| Parameter | Default | Description |
|---|---|---|
| `alignment_kp` | 0.003 | P-controller gain for angular alignment |
| `max_angular_vel` | 0.5 | Maximum turn speed during alignment |
| `station_a_delay_after_ball_1` | 4.7 | Seconds to wait after ball 1 at Station A |
| `station_a_delay_after_ball_2` | 0.7 | Seconds to wait after ball 2 at Station A |
| `station_b_delay_after_ball_*` | 0.0 | No delays at Station B |

## simple_mission_fsm.py - Deep Dive

### What It Does
Demonstrates clean FSM patterns with just 4 states:
1. Wait for services to be ready
2. Enable exploration
3. When marker seen, stop exploring and dock
4. Done

### Why It Exists
- Teaching tool for clean FSM design
- Debug tool for testing exploration -> docking flow
- Simpler than full mission_controller for isolated testing

### Important Pattern: Callback Discipline
```
RULE: Callbacks ONLY write flags. They NEVER call transition_to().
```
This is the single most important design rule in the FSM. It prevents race conditions and makes the state machine deterministic - all transitions happen in one place (the 10Hz tick).

---

**See also:** [[State Machine Reference]], [[Architecture Overview]]

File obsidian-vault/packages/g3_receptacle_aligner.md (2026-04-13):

# g3_receptacle_aligner

> **Type:** Standalone Python scripts (not a proper ROS2 package)
> **Purpose:** Hough circle detection to align robot with tin receptacles at stations

## Files

| File | Purpose |
|---|---|
| `station_a_aligner.py` | Linear P-control alignment for Station A (static tin) |
| `station_b_aligner.py` | Alignment for Station B (moving receptacle) |

## station_a_aligner.py - Deep Dive

### What It Does
Detects the circular tin opening using Hough circle detection, then drives the robot forward/backward (linear only, no turning) to center the circle in the camera frame.

### Detection Pipeline

```
Compressed Image (/camera/image_raw/compressed)
    │
    ▼
JPEG decode → BGR frame
    │
    ▼
Grayscale → GaussianBlur (11x11, sigma=2)
    │
    ▼
HoughCircles (dp=1.2, minDist=100, param1=50, param2=25, r=41-61)
    │
    ▼
Pick largest circle → Darkness check (reject bright acrylic)
    │
    ▼
Temporal filter (4 consecutive hits to confirm)
    │
    ▼
EMA smoothing (alpha=0.35) on center x-coordinate
    │
    ▼
P-control: linear_vel = KP * (cx - center_x)
```

### Darkness Check
**Problem:** Hough circles also detect reflections on acrylic walls.
**Solution:** Sample the interior of detected circle. Real tin is dark (mean gray < 100). Acrylic is bright. Reject circles with bright interiors.

```python
# Sample inner 60% of radius
sr = max(3, int(r * 0.6))
mask = np.zeros(gray.shape, dtype=np.uint8)
cv2.circle(mask, (cx, cy), sr, 255, -1)
mean_inside = cv2.mean(gray, mask=mask)[0]
if mean_inside > 100:  # too bright = acrylic, not tin
    reject
```

### P-Control

Only **linear** (forward/backward) control. No rotation.
- `offset > 0` (tin is right of center) -> drive forward
- `offset < 0` (tin is left of center) -> drive backward
- `|offset| < 15px` -> aligned, stop

```python
KP_LINEAR = 0.002
MAX_LINEAR_VEL = 0.08
linear_vel = clamp(KP * offset, -0.08, 0.08)
```

### Published Topics

| Topic | Type | Rate | Purpose |
|---|---|---|---|
| `/receptacle/offset` | Int32 | ~30Hz | Pixel offset (9999 = not detected) |
| `/receptacle/aligned` | Bool | ~30Hz | True when centered |
| `/receptacle/tin_ready` | Bool | ~30Hz | Same as aligned for Station A |
| `/receptacle/annotated` | Image | ~30Hz | Debug overlay |
| `/cmd_vel` | Twist | ~30Hz | Linear-only velocity |

### Parameters (Hardcoded)

| Param | Value | Purpose |
|---|---|---|
| `KP_LINEAR` | 0.002 | Pixels to m/s gain |
| `MAX_LINEAR_VEL` | 0.08 m/s | Speed cap |
| `ALIGN_THRESHOLD` | 15 px | "Aligned" if offset within this |
| `MIN_R` / `MAX_R` | 41 / 61 px | Hough circle radius range |
| `CONFIRM_FRAMES` | 4 | Consecutive detections required |
| `EMA_ALPHA` | 0.35 | Smoothing factor |
| `DARKNESS_THRESHOLD` | 100 | Max mean gray for valid circle |

### Integration with Mission Controller
The mission controller's `offset_callback()` ALSO does P-control (angular, not linear) based on `/receptacle/offset`. There's a potential conflict:
- `station_a_aligner` publishes linear commands on `/cmd_vel`
- `mission_controller` publishes angular commands on `/cmd_vel`
- Both run simultaneously during ALIGN_AT_A state

This works because the aligner only sets `linear.x` and the mission controller only sets `angular.z` -- but they publish separate Twist messages, so **the last one wins**. In practice, the aligner publishes at camera rate (~30Hz) and the mission controller at 10Hz + camera rate, so commands interleave.

> **Potential Issue:** This interleaving means some `/cmd_vel` messages have linear but no angular, and vice versa. A proper design would have a single node combining both.

---

**See also:** [[g3_mission_control]], [[State Machine Reference]]

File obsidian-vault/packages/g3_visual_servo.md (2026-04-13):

# g3_visual_servo

> **Type:** `ament_python` package
> **Purpose:** ArUco marker detection, visual servoing, and docking

## Files

| File | Lines | Purpose |
|---|---|---|
| `aruco_dock_node.py` | ~410 | Legacy docking: detect + PI control + drive |
| `aruco_dock_pose_publisher.py` | ~293 | New: detect + publish pose for Nav2 docking |
| `dock_test.py` | ? | Manual docking test |
| `turn_calibrate.py` | ? | Turn calibration utility |
| `cmd_vel_test.py` | ? | Smoke test for velocity commands |

## Launch Files

| File | Purpose |
|---|---|
| `aruco_dock.launch.py` | Hardware docking launch |
| `aruco_dock_hw_test.launch.py` | Hardware test with Nav2 docking server |

## Entry Points

```python
'aruco_dock = g3_visual_servo.aruco_dock_node:main'
'aruco_dock_pose_publisher = g3_visual_servo.aruco_dock_pose_publisher:main'
'dock_test = g3_visual_servo.dock_test:main'
'turn_calibrate = g3_visual_servo.turn_calibrate:main'
'cmd_vel_test = g3_visual_servo.cmd_vel_test:main'
```

---

## aruco_dock_node.py - The Legacy Docking System

### How ArUco Detection Works

1. Camera publishes images on `/usb_cam/image_raw`
2. Convert to grayscale
3. `cv2.aruco.detectMarkers()` finds marker corners
4. `cv2.solvePnP()` estimates 6DOF pose from known marker size
5. Extract bearing (arctan2) and distance (norm of tvec)

### Marker Size = 0.165m
The physical marker is 16.5cm on each side. This must be accurate or solvePnP gives wrong distance.

### Two Modes

**Passive (SCANNING):**
- Detects any marker in `{42, 67}`
- Publishes robot's map-frame pose to `/station_a_pose` or `/station_b_pose`
- Uses TF lookup (`map` -> `base_link`) to get robot position
- Does NOT move the robot

**Active (APPROACHING):**
- Triggered by `/aruco_dock/dock_to_a` or `dock_to_b` service
- Tracks only the requested marker
- PI control loop drives robot toward marker
- Stops at `DOCK_DIST = 0.30m`

### PI Control Explained

```
bearing = arctan2(marker_x_in_camera, marker_z_in_camera)
distance = norm(tvec)

angular_z = -KP_ANGULAR * bearing_ema    (turn to face marker)
linear_x  = KP_LINEAR * dist_error + KI_LINEAR * integral  (drive forward)

Only drive forward when:
  - bearing < 15 degrees (roughly facing marker)
  - distance > dock_distance (not yet close enough)
```

### EMA Smoothing
Raw solvePnP measurements are noisy. Exponential Moving Average (alpha=0.3) smooths both bearing and distance:
```
new_ema = alpha * raw_measurement + (1 - alpha) * old_ema
```

### OpenCV Compatibility
The code handles both OpenCV 4.6 (Debian) and 4.7+ APIs:
- 4.6: `aruco.Dictionary_get()`, `aruco.DetectorParameters_create()`
- 4.7+: `aruco.getPredefinedDictionary()`, `aruco.DetectorParameters()`
- Also forces arrays to be contiguous (`np.ascontiguousarray`) to avoid 4.6 segfaults

---

## aruco_dock_pose_publisher.py - The New Nav2-Compatible System

### What's Different
- **NO state machine** - purely detection -> publish
- **NO /cmd_vel** - doesn't drive the robot at all
- **NO TF lookups** - publishes in camera frame, not map frame
- Just: detect marker -> solvePnP -> publish PoseStamped on `/detected_dock_pose`

### Why This Exists
Nav2's `opennav_docking` framework (specifically `SimpleNonChargingDock` plugin) expects an external node to publish the dock's pose. The docking server handles all the approach control itself. This clean separation is better architecture.

### Key Implementation Detail: Timestamps
```python
out.header.stamp = msg.header.stamp  # Use image timestamp, NOT current time
```
The docking server has an `external_detection_timeout` - if the timestamp is stale, it considers the detection lost. Using the image's own timestamp ensures freshness checks work correctly.

### Quaternion Conversion
Since this node avoids importing `tf_transformations` (to avoid a dependency), it implements rotation-matrix-to-quaternion conversion manually using the standard trace-based algorithm.

### Parameters

| Parameter | Default | Description |
|---|---|---|
| `image_topic` | `/camera/image_raw` | Camera feed |
| `camera_info_topic` | `/camera/camera_info` | Camera intrinsics |
| `dock_pose_topic` | `/detected_dock_pose` | Output topic |
| `target_marker_id` | 42 | Which ArUco ID to track |
| `marker_size` | 0.165 | Marker edge length (meters) |
| `dictionary` | `DICT_4X4_100` | ArUco dictionary |
| `output_frame_id` | `""` | Override frame_id (empty = use camera's) |

---

**See also:** [[ArUco Markers Explained]], [[PI Control for Docking]]

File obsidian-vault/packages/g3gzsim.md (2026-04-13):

# g3gzsim

> **Type:** `ament_cmake` package
> **Purpose:** Gazebo simulation worlds, robot models, launch files, and Nav2 parameter configs

## Directory Structure

```
g3gzsim/
├── launch/
│   ├── sim_only_launch.py              # Gazebo only, no Nav2
│   ├── nav2full_test_launch.py         # Full sim: Gazebo + Nav2 + SLAM + exploration
│   └── nav2_docking_sim_test.launch.py # Docking test: Gazebo + Nav2 + ArUco detector
├── worlds/
│   ├── square_room.sdf     # Simple 4-wall room with ArUco marker on east wall
│   ├── warehouse_world.sdf # More complex warehouse layout
│   └── tutorial_world.sdf  # Gazebo tutorial world
├── models/
│   ├── aruco_marker_42/    # ArUco marker ID 42 (Station A)
│   ├── aruco_marker_67/    # ArUco marker ID 67 (Station B)
│   └── turtlebot3_world/   # TurtleBot3 world model
├── urdf/
│   └── tb.sdf.xacro        # TurtleBot3 robot model with camera
├── nav2/
│   └── nav2_params.yaml    # Nav2 parameters for simulation
├── rviz/
│   └── nav2_default_view.rviz # RViz display config
└── CMakeLists.txt
```

## Launch Files

### `sim_only_launch.py`
Minimal launch: just Gazebo + robot + camera bridges. No Nav2, no SLAM.
Good for: Testing camera/sensor output, world design.

### `nav2full_test_launch.py`  
Full simulation stack:
- Gazebo with square_room world
- TurtleBot3 with camera
- Nav2 (SLAM mode, no static map)
- Camera bridges (image + camera_info)
- Frontier exploration node
- Simple mission FSM

This is the main simulation launch for full-stack testing.

### `nav2_docking_sim_test.launch.py`
Docking-specific test:
- Gazebo with square_room (includes ArUco marker 42 on east wall)
- TurtleBot3 spawned at (-2, 0) facing east toward marker
- Nav2 with SLAM and **docking_server** enabled
- Camera bridges
- `aruco_dock_pose_publisher` node

Manual test command after launch:
```bash
ros2 action send_goal /dock_robot nav2_msgs/action/DockRobot "{
  use_dock_id: false,
  dock_pose: {header: {frame_id: 'map'}, 
    pose: {position: {x: 2.0, y: 0.0, z: 0.0}, orientation: {w: 1.0}}},
  dock_type: 'aruco_dock',
  navigate_to_staging_pose: true
}" --feedback
```

## ArUco Marker Models

### aruco_marker_42
- A 0.18m square SDF model with marker 42 texture
- Placed on the east wall of `square_room.sdf`
- Used for docking tests and Station A simulation

### aruco_marker_67  
- Same structure, marker 67 texture
- Station B marker
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

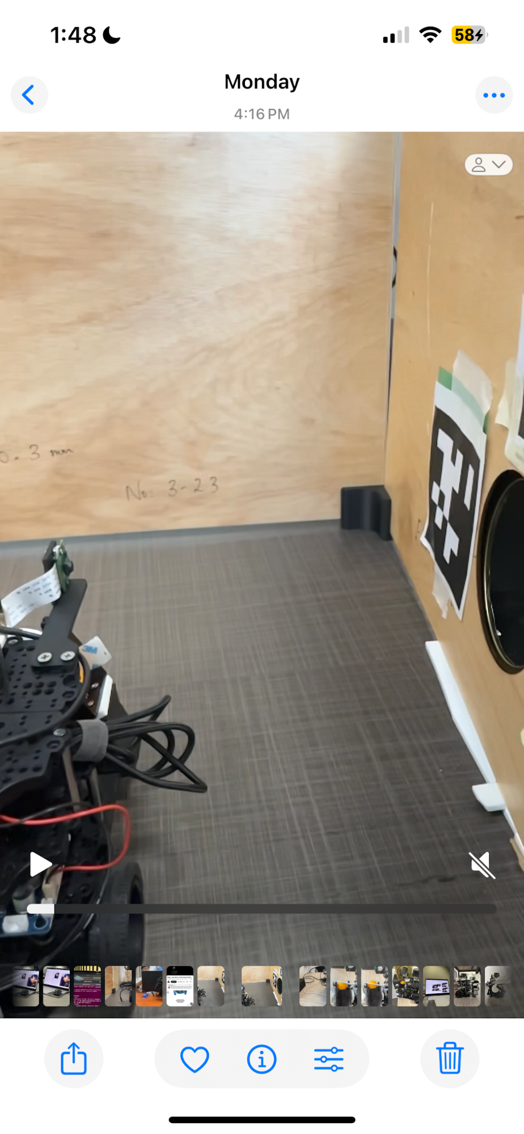
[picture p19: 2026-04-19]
docs/assets/g2-report/dock1.png

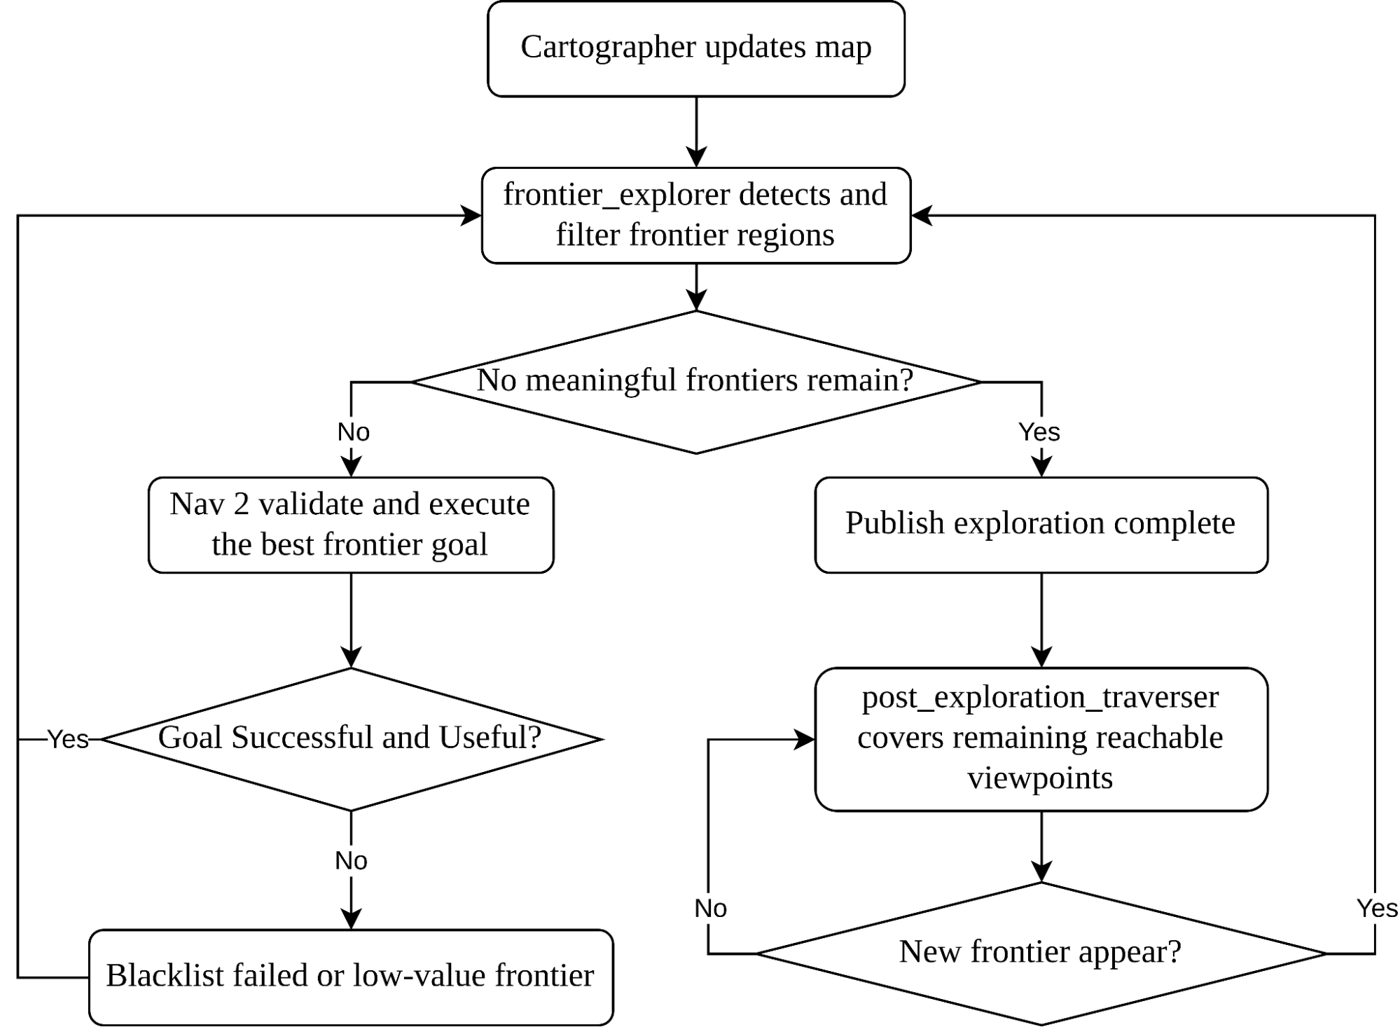
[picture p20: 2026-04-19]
docs/assets/g2-report/navexploreflow.png

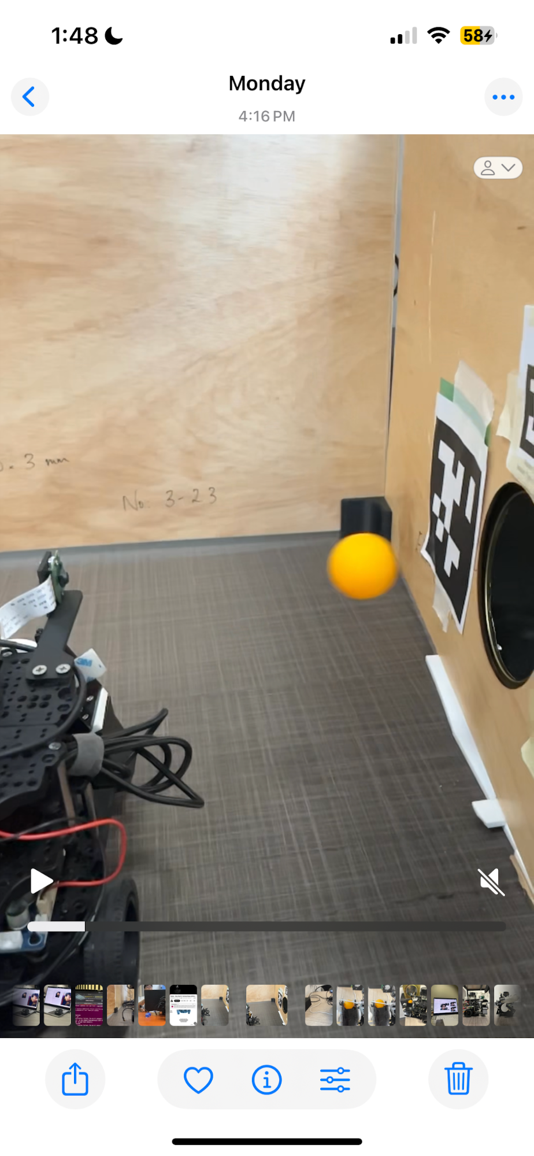
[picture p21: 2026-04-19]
docs/assets/g2-report/launch14.png

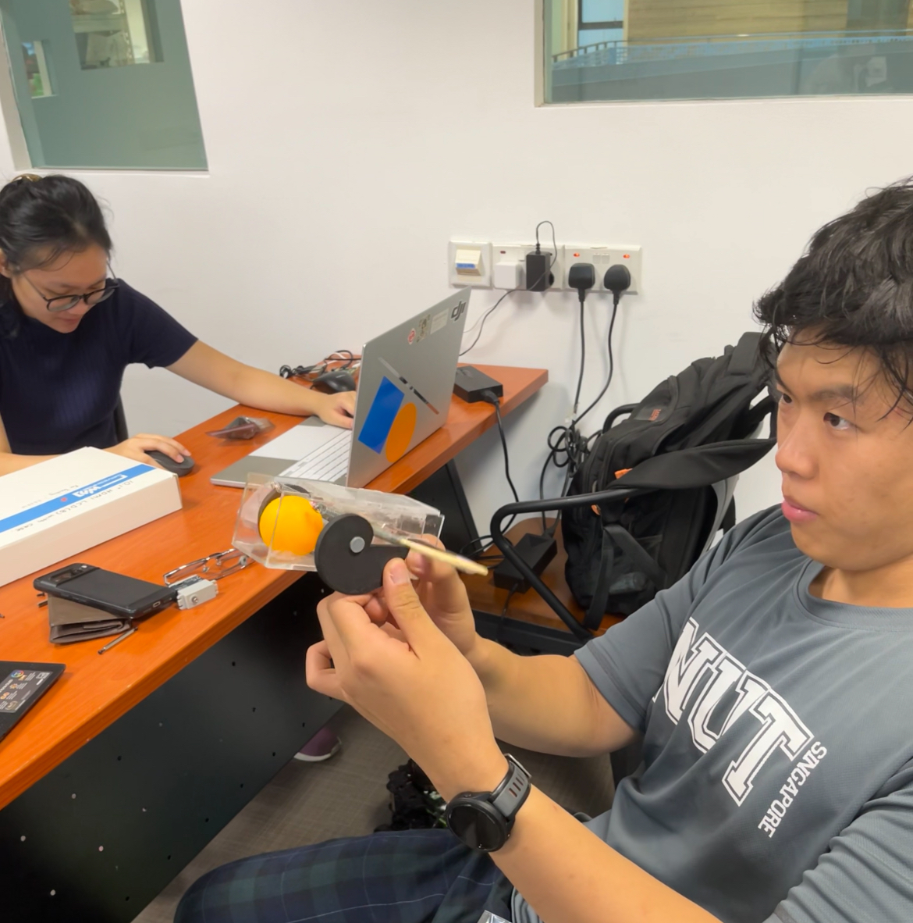
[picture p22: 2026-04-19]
docs/assets/g2-report/launch15.jpg

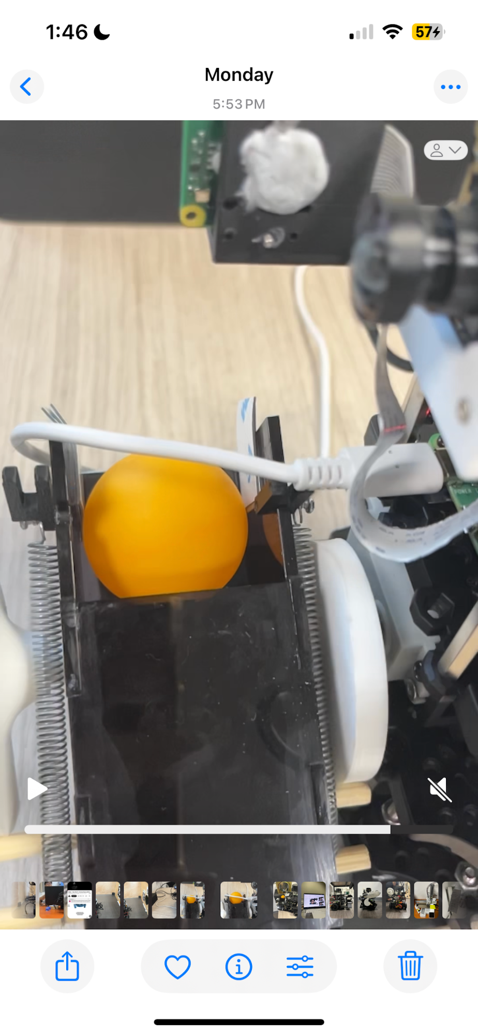
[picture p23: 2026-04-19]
docs/assets/g2-report/launch7.png

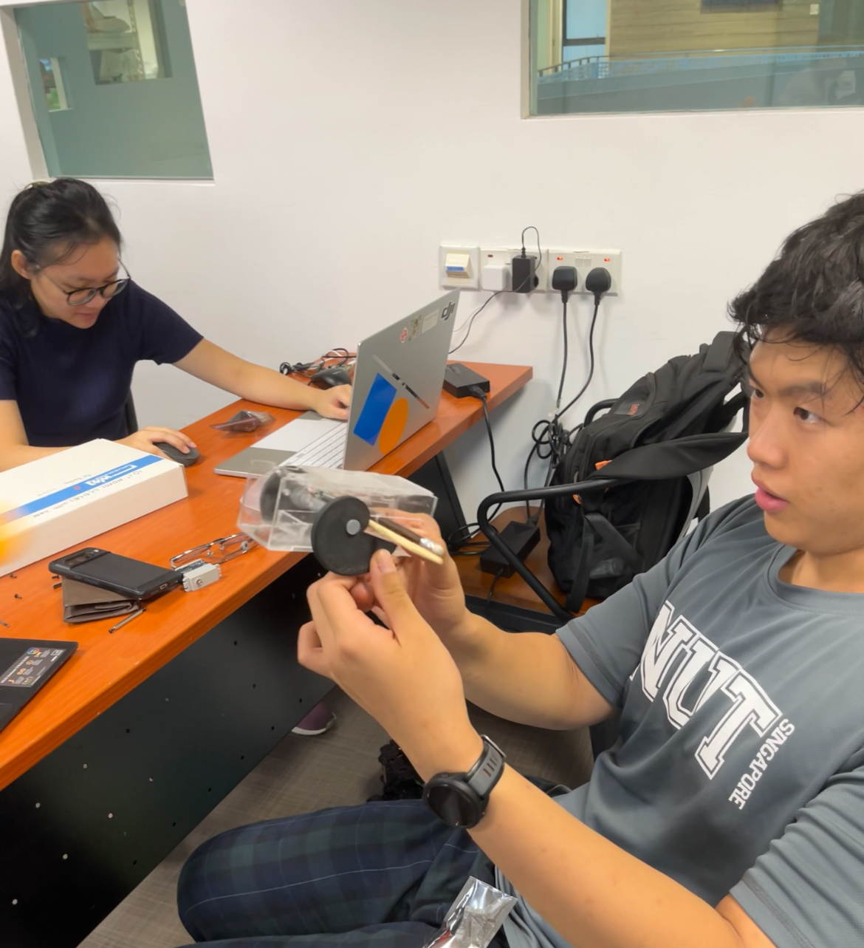
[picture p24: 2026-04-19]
docs/assets/g2-report/launch2.jpg

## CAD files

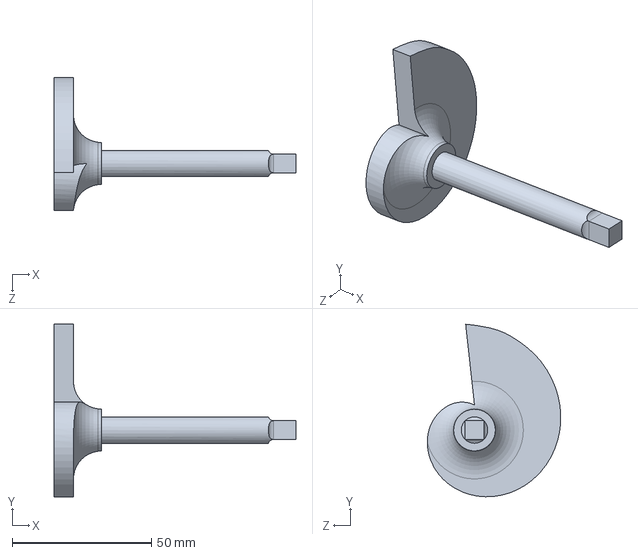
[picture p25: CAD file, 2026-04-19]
mech/cad_files/Shaft v2.SLDPRT
87.0 x 62.0 x 48.0 mm

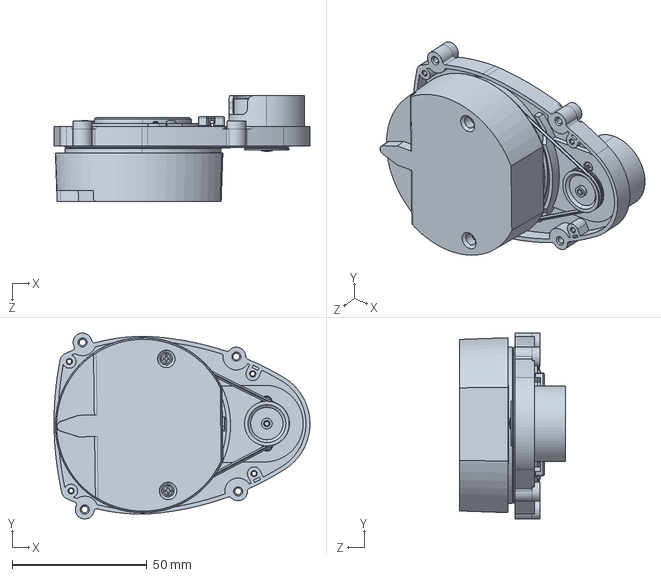
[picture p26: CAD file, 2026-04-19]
mech/cad_files/Turtlebot/LiDAR.step.SLDPRT
95.0 x 69.0 x 39.2 mm

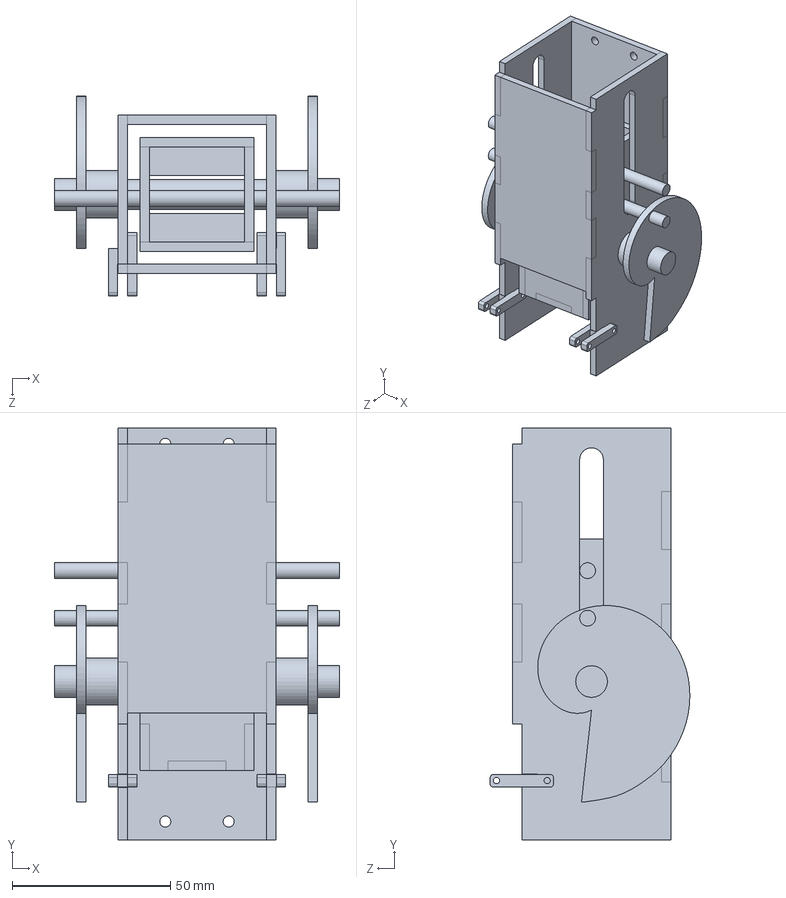
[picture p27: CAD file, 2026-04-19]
mech/cad_files/launchmechanismv2.SLDPRT
90.0 x 130.0 x 63.0 mm

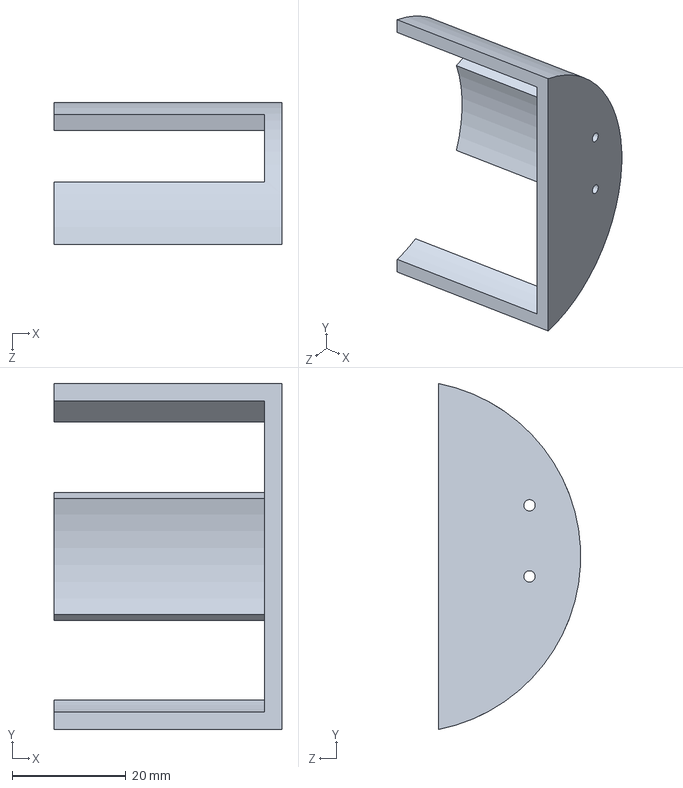
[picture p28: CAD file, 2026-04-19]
mech/cad_files/Pipe Deadend.SLDPRT
40.0 x 60.8 x 25.0 mm

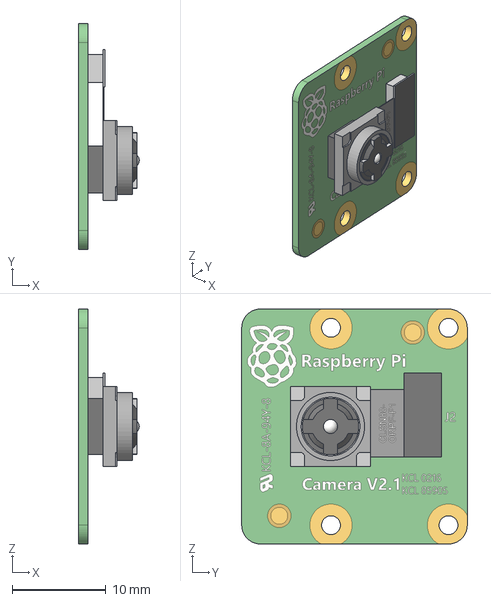
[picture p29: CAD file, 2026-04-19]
mech/cad_files/RPi Camera.step
6.45 x 24.0 x 25.0 mm

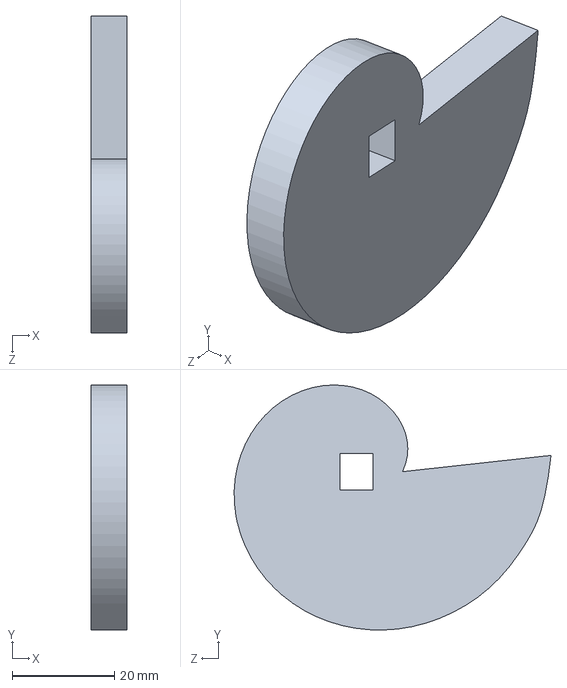
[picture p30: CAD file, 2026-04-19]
mech/cad_files/camv2.SLDPRT
7.00 x 48.0 x 62.0 mm

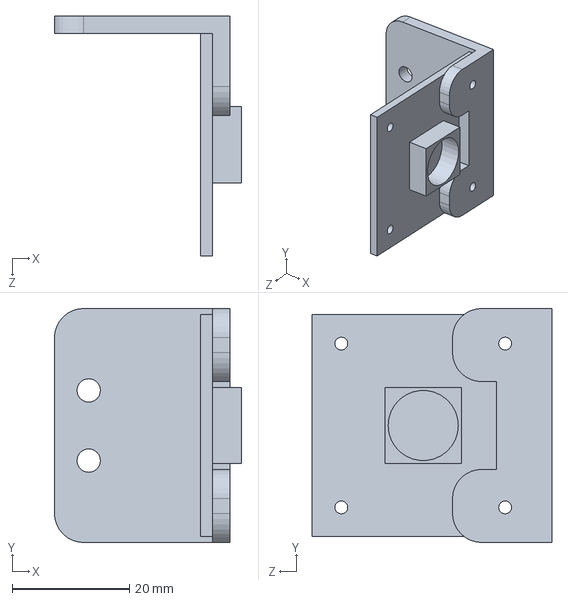
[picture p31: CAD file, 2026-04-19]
mech/cad_files/USB Camera.SLDPRT
32.0 x 40.0 x 41.0 mm

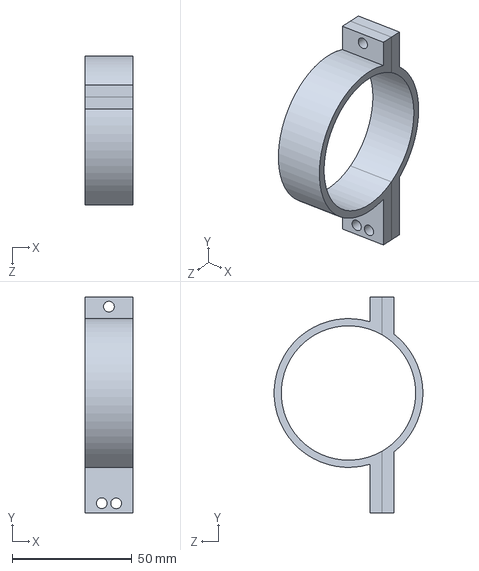
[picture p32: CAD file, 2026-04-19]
mech/cad_files/Feeder Clamp.SLDPRT
20.0 x 90.0 x 61.9 mm

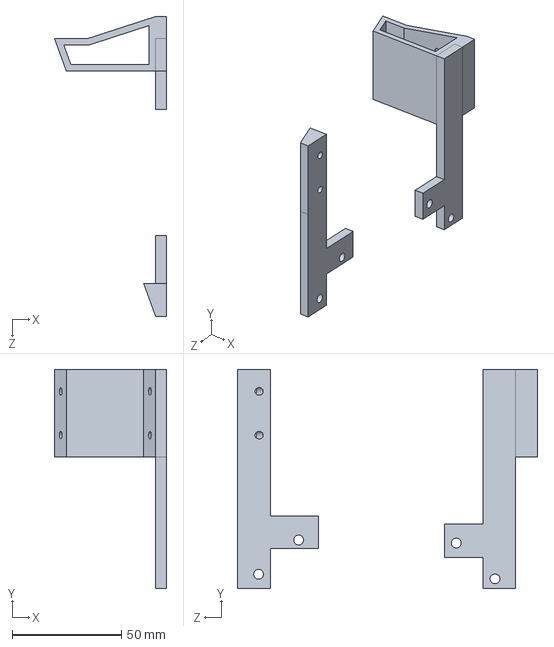
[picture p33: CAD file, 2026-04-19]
mech/cad_files/launchermount.SLDPRT
51.2 x 100.0 x 137.0 mm

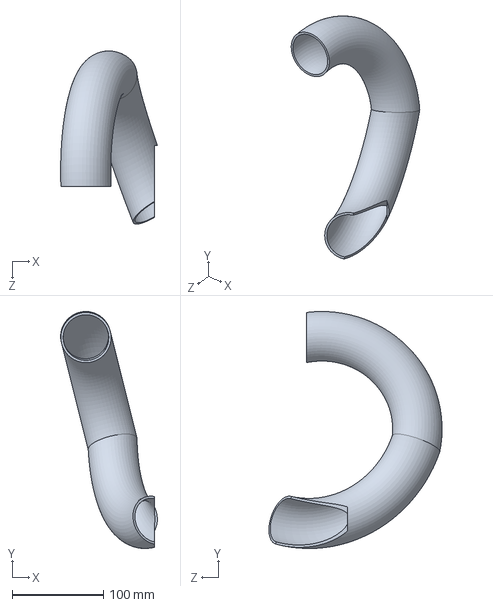
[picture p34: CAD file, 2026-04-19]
mech/cad_files/Feeder.SLDPRT
105.9 x 259.5 x 189.6 mm

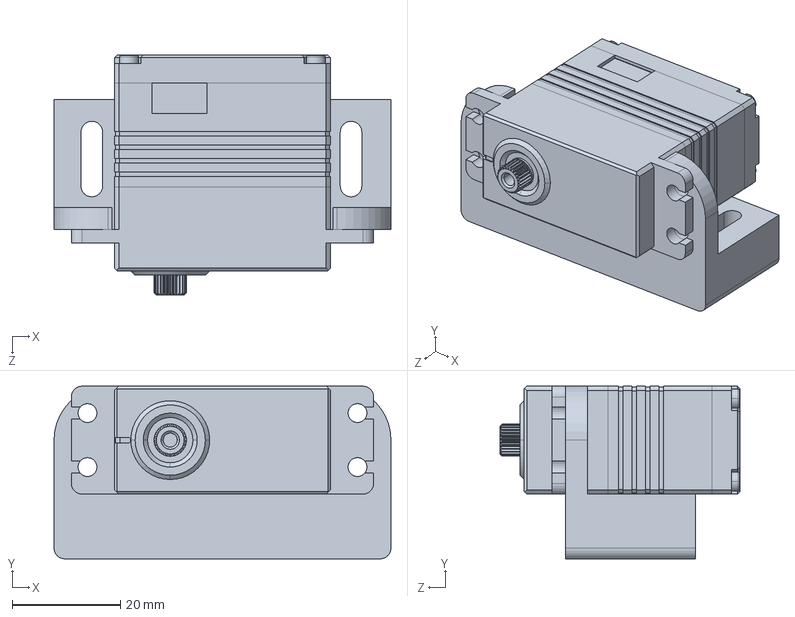
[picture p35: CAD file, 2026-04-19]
mech/cad_files/Servo HLU125 Model.SLDPRT
62.4 x 32.0 x 44.5 mm

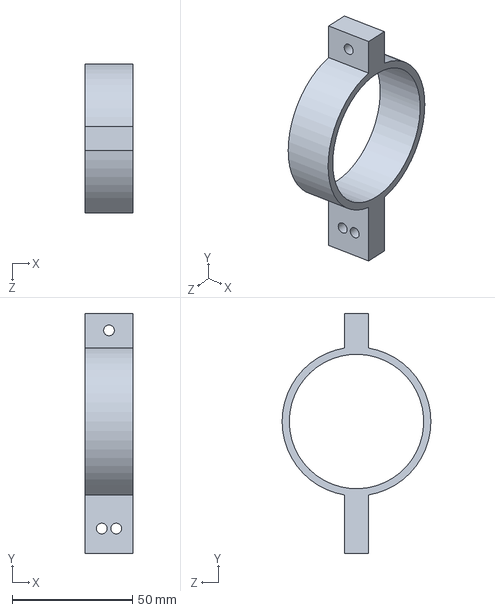
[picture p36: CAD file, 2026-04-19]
mech/cad_files/Feeder Clamp 0.5.SLDPRT
20.0 x 100.0 x 62.0 mm

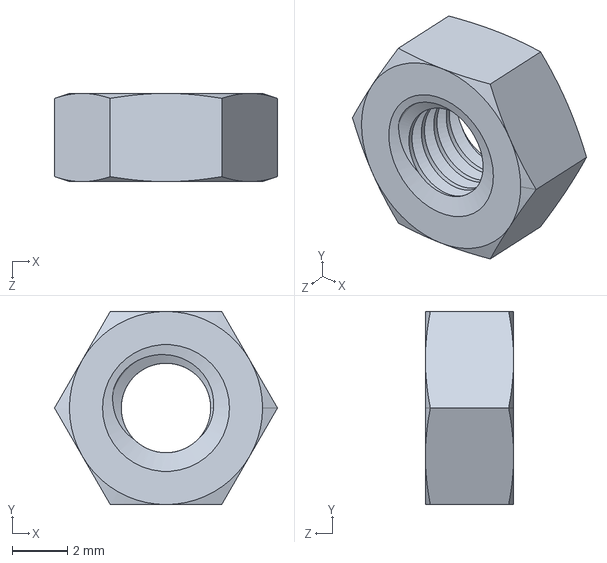
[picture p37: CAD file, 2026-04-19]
mech/cad_files/M4_nut.SLDPRT
8.08 x 7.00 x 3.20 mm

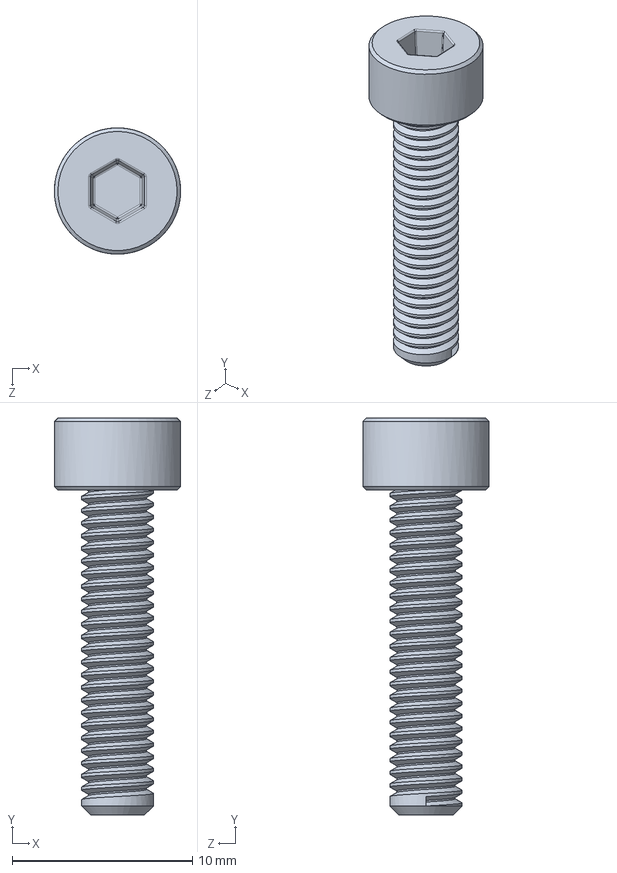
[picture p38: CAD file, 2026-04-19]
mech/cad_files/M4x10.SLDPRT
7.00 x 22.0 x 7.00 mm

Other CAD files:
mech/cad_files/M2 x 0.4mm Thread 12mm LONG SOCKET HEAD CAP SCREW.STEP
mech/cad_files/RPi Camera.SLDPRT

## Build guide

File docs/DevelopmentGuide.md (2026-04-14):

## Portable Docker Development Environment

This repo now includes a portable Docker setup built on top of the official `osrf/ros:jazzy-desktop` image (Ubuntu 24.04 / Noble) with:

- `ros-jazzy-desktop`
- `ros-dev-tools`
- Gazebo Harmonic (`gz-harmonic`)
- Nav2 + Cartographer dependencies
- Foxglove bridge
- TurtleBot3 built from source in `~/turtlebot3_ws`

### 1. Clone the repo to `~/nav_ws`

```bash
git clone git@github.com:Chesium/r2auto_nav_CDE2310.git -b jazzystack ~/nav_ws
cd ~/nav_ws
```

### 2. Build the image

Default Linux user mapping is `1000:1000`, which is usually correct for Ubuntu and WSL2. If your user/group IDs differ, export them before building:

```bash
export DEV_UID=$(id -u)
export DEV_GID=$(id -g)
docker compose build
```

### 3. Create the editable ROS network config

The container will auto-create `docker/ros_network.env` from the example on first start, or you can do it yourself:

```bash
cp docker/ros_network.env.example docker/ros_network.env
```

Edit [docker/ros_network.env.example](docker/ros_network.env.example) as a reference, and keep your machine-specific values in `docker/ros_network.env`.

The values intended for quick changes are:

- `ROS_DISCOVERY_SERVER`
- `ROS_DOMAIN_ID`
- `ROS_DISCOVERY_INTERFACE`
- `ROS_DISCOVERY_PORT`

By default, `docker/ros_network.env` now leaves `ROS_DISCOVERY_SERVER` unset so terminals inside the same dev container use normal ROS 2 peer discovery immediately. Only set `ROS_DISCOVERY_SERVER` when you are intentionally using a Fast DDS discovery server for laptop/robot communication.

### 4. Start the dev container

Native Ubuntu 22.04 / 24.04:

```bash
xhost +local:docker
docker compose -f docker-compose.linux-host.yml up -d
docker compose -f docker-compose.linux-host.yml exec dev bash
```

WSL2 with Ubuntu 22.04 / 24.04 and WSLg:

```bash
docker compose -f docker-compose.yml -f docker-compose.wslg.yml up -d
docker compose -f docker-compose.yml -f docker-compose.wslg.yml exec dev bash
```

Inside the container, the shell auto-sources:

- `/opt/ros/jazzy/setup.bash`
- `~/turtlebot3_ws/install/setup.bash`
- `~/nav_ws/install/setup.bash` when it exists

and defines these commands:

- `roset`
- `talker`
- `topics`
- `foxnode`
- `slam`
- `rteleop`
- `discovery`

For a quick local sanity check inside the container, open two shells and run:

```bash
talker
```

```bash
ros2 node list
```

You should see `/talker` without needing `discovery`.

### 5. Build this workspace inside the container

```bash
cd ~/nav_ws
colcon build --symlink-install
roset
```

### VS Code Dev Container

This repo also includes [.devcontainer/devcontainer.json](.devcontainer/devcontainer.json), so in VS Code you can:

```bash
code ~/nav_ws
```

then run `Dev Containers: Reopen in Container`.

By default the devcontainer uses [docker-compose.yml](docker-compose.yml), which is the more portable choice across Ubuntu and WSL2. If you are on native Ubuntu and want host networking from inside VS Code for robot communication, change the `dockerComposeFile` entry in [.devcontainer/devcontainer.json](.devcontainer/devcontainer.json) to `../docker-compose.linux-host.yml`.

### Notes on portability

- Ubuntu 22.04 and WSL2 Ubuntu 22.04 are fine as *hosts* because Docker isolates the userland; the container itself still runs Ubuntu 24.04, which is the supported binary platform for ROS 2 Jazzy.
- Native Ubuntu is the best option when you need ROS 2 discovery and real robot networking to behave like a normal Linux machine.
- WSL2 is excellent for editing and local builds, and usually fine for Gazebo/RViz when WSLg is working well, but real LAN robotics workflows are a little more sensitive to Docker/WSL networking.
- If you mainly want simulation, WSL2 is usually convenient enough. If you need to talk to the robot over the same network as the laptop, native Ubuntu will be more predictable.
- If Foxglove is all you need from outside the container, the base compose file publishes port `8765`.

## Run Simulation

```bash
colcon build
source install/setup.bash
ros2 launch g3gzsim nav2full_test_launch.py
```

in one line: (assume you have `alias roset="source install/setup.bash"` in `~/.bashrc`)

```bash
colcon build && roset && ros2 launch g3gzsim nav2full_test_launch.py | tee test.log
```

---

then, to activate the explorer, in a new terminal, run:

```bash
ros2 service call /exploration/set_enabled std_srvs/srv/SetBool "{data: true}"
```

## Update/Connect to Hot-spot and establish ROS 2 Connection

- `sudo nmtui`: Activate the connection > Find the hot-spot, connect it (this time is without password and the program will stuck)
- wait a few seconds, restart the RPi, `ssh g3@rpi` (via Tailscale), then run `sudo nmtui` again : Edit a Connection > edit the password and disable automatic connect.
- use `sudo nmcli c up [NAME]` to activate the connection (replace `[NAME]` with the hot-spot name), you may have to wait a bit, you can also run `ssh g3@rpi` in a new laptop terminal to monitor its progress
- after connection, use `ip a` to find its IP address under the hot-spot connection:

```
3: wlan0: <BROADCAST,MULTICAST,UP,LOWER_UP> mtu 1500 qdisc fq_codel state UP group default qlen 1000
    link/ether d8:3a:dd:23:92:0f brd ff:ff:ff:ff:ff:ff
    inet 172.20.10.9/28 brd 172.20.10.15 scope global dynamic noprefixroute wlan0
       valid_lft 2627sec preferred_lft 2627sec
    inet6 fe80::7126:5b15:305f:2030/64 scope link noprefixroute 
       valid_lft forever preferred_lft forever
```

- example output above: ip should be `172.20.10.9`
- connect the same hot-spot on your laptop (if no ethernet and we are using phone hot-spot) and verify we can ssh into the rpi via the ip we just obtained `ssh g3@172.20.10.9` (type `yes` if necessary)
- **Important for ROS 2 Connection:** On Laptop, first edit `docker/ros_network.env` so `ROS_DISCOVERY_SERVER` and `ROS_DISCOVERY_INTERFACE` both use the laptop's actual reachable IP, then run `discovery` in a terminal **before doing anything about ROS 2** after reboot or connect to a new hot-spot
- **Important for ROS 2 Connection:** edit the `~/.bashrc` on **Both RPI and the laptop**: add or modify the `ROS_DISCOVERY_SERVER` IP to be the same as the **laptop** IP (obtain also by running `ip a`)

```bash
export RMW_IMPLEMENTATION=rmw_fastrtps_cpp
export ROS_SUPER_CLIENT=TRUE
export ROS_DISCOVERY_SERVER=10.42.0.1:11811 # <- change this to *LAPTOP* IP
export ROS_DOMAIN_ID=32
```

- `source ~/.bashrc` on both rpi and laptop
- restart ROS daemon **on both RPi and laptop** by doing
  - `ros2 daemon stop`
  - `ros2 daemon start`
- verify the ros 2 connection by
  - on rpi, running `ros2 run demo_nodes_cpp talker`
  - on laptop, running `ros2 topic list` (maybe twice for the change to be updated) and verify you see the `/chatter` topic being published by the RPI talker node

## Setup Foxglove Dashboard

- ensure you have downloaded it on your laptop
- follow [this](https://docs.foxglove.dev/docs/getting-started/frameworks/ros2#foxglove-websocket) to install the packages and activate the foxglove node by running:
  - `ros2 launch foxglove_bridge foxglove_bridge_launch.xml`
    - you can set an alias for this ("foxnode")
- open foxglove, connect via `ws://localhost:8765`

## Setup Camera

- after verifying that the ROS 2 Connection is fine, run

```bash
sudo bash -ic 'source /home/g3/.bashrc && source /home/g3/camera_ws/install/setup.bash && ros2 run camera_ros camera_node --ros-args -p format:=BGR888 -p camera:=0 -p role:=viewfinder -p height:=240 -p width:=320'
```

- it's fine if you see `unable to open camera calibration file` Error.
- in Foxglove, add a *image* panel and open the `/camera/image_raw/compressed` topic to monitor the image flow
- force kill the node by `sudo pkill -9 camera_node`

## Setup Nav 2

- after verifying that the ROS 2 Connection is fine, run `rosbu` on RPi to activate the robot_state / lidar / motor publisher stuff.
  - verify on laptop by `ros2 topic list`
  - verify you can teleoperate it by `ros2 run turtlebot3_teleop teleop_keyboard` ([reference](https://emanual.robotis.com/docs/en/platform/turtlebot3/basic_operation/#basic-operation))
- build `g3nav2` and run `ros2 launch g3nav2 g3nav2_bringup_launch.py`
  - this line is equal to the following which are packaged into our launch file
  - currently the parameter is the same as the default `burger.yaml` except for:
  - `collision_monitor > scan > source_timeout`: changed from `0.2` to `1.0` (line 414)

- run slam on your laptop **without RViz UI** (since we will open an another one when activating nav 2) by `slam use_rviz:=false`
  - assuming you have set `alias slam="ros2 launch turtlebot3_cartographer cartographer.launch.py"`
- run the nav2 launch file: `ros2 launch turtlebot3_navigation2 navigation2.launch.py map:='""'`
  - after you see the costmap overlay (blue/purple/red stuff), do a round of `2D pose Estimate` (not sure if this is compulsory)

## Misc stuff

ros2 launch nav2_bringup tb3_simulation_launch.py headless:=False

use slam instead of fixed map server

ros2 launch nav2_bringup tb3_simulation_launch.py headless:=False slam:=True map:='""'

ros2 launch nav2_bringup tb3_simulation_launch.py headless:=False slam:=True map:='""' x_pose:=0 y_pose:=0

empirical suggestion: close rviz2 first, then gazebo

ref: https://robotics.stackexchange.com/questions/87696/provide-empty-string-as-roslaunch-argument-substitution

package flow of the parameter `map`:
- `nav2_bringup/launch/tb3_simulation_launch.py` : `"map" - map_yaml_file`
- `nav2_bringup/launch/bringup_launch.py` : `"map" - map_yaml_file`
- `nav2_bringup/launch/localization_launch.py` : `"map" - map_yaml_file`
  - `nav2_map_server@map_server` : `"yaml_filename"`
  - `[Composable] nav2_map_server::MapServer` : `"yaml_filename"`

next step: use customized world file

there's also a `pose` parameter in the top launch file

```bash
ros2 pkg create --build-type ament_cmake --license Apache-2.0 g3description
ros2 pkg create --build-type ament_python --license Apache-2.0 g3gzsim
ros2 pkg create --build-type ament_python --license Apache-2.0 g3navigation
ros2 pkg create --build-type ament_python --license Apache-2.0 g3bringup
ros2 pkg create --build-type ament_python --license Apache-2.0 g3exploration
```

note for servo: might need to run pip install pyserial --break-system-packages in dev container

recommended file tree by Chat-GPT:

```
your_ws/
└── src/
    ├── your_robot_description/
    │   ├── package.xml
    │   ├── CMakeLists.txt / setup.py
    │   ├── urdf/
    │   │   ├── robot.urdf.xacro
    │   │   ├── robot_core.xacro
    │   │   ├── sensors.xacro
    │   │   └── ros2_control.xacro
    │   ├── meshes/
    │   │   ├── base.dae
    │   │   ├── wheel.dae
    │   │   └── ...
    │   ├── materials/              # optional
    │   ├── rviz/                   # optional if model-only RViz config
    │   │   └── view_robot.rviz
    │   └── launch/
    │       └── display.launch.py   # robot_state_publisher + joint_state_publisher_gui
    │
    ├── your_robot_gazebo/
    │   ├── package.xml
    │   ├── CMakeLists.txt / setup.py
    │   ├── worlds/
    │   │   ├── lab.sdf
    │   │   ├── empty.sdf
    │   │   └── ...
    │   ├── sdf/
    │   │   ├── robot_gz.sdf.xacro
    │   │   └── sensors_gz.sdf.xacro
    │   ├── models/                 # optional for standalone Gazebo models
    │   ├── launch/
    │   │   ├── sim.launch.py
    │   │   ├── spawn_robot.launch.py
    │   │   └── world_only.launch.py
    │   └── config/
    │       └── gazebo_bridge.yaml  # if using ros_gz bridge
    │
    ├── your_robot_navigation/
    │   ├── package.xml
    │   ├── CMakeLists.txt / setup.py
    │   ├── launch/
    │   │   ├── nav_sim.launch.py
    │   │   ├── nav_real.launch.py
    │   │   ├── localization.launch.py
    │   │   ├── slam.launch.py
    │   │   └── rviz.launch.py
    │   ├── params/
    │   │   ├── nav2_common.yaml
    │   │   ├── nav2_sim.yaml
    │   │   ├── nav2_real.yaml
    │   │   ├── localization.yaml
    │   │   ├── slam_toolbox.yaml
    │   │   └── planner_tuning.yaml
    │   ├── rviz/
    │   │   ├── nav_default.rviz
    │   │   ├── nav_debug.rviz
    │   │   └── localization.rviz
    │   ├── maps/
    │   │   ├── office.yaml
    │   │   ├── office.pgm
    │   │   └── ...
    │   ├── behavior_trees/         # if you customize Nav2 BTs
    │   │   └── navigate_w_recovery.xml
    │   └── config/                 # non-Nav2 YAMLs
    │       ├── costmap_filters.yaml
    │       └── route_graph.geojson
    │
    ├── your_robot_bringup/
    │   ├── package.xml
    │   ├── CMakeLists.txt / setup.py
    │   ├── launch/
    │   │   ├── bringup_sim.launch.py
    │   │   ├── bringup_real.launch.py
    │   │   ├── sensors.launch.py
    │   │   ├── drivers.launch.py
    │   │   └── teleop.launch.py
    │   └── config/
    │       ├── ekf.yaml
    │       ├── lidar.yaml
    │       ├── camera.yaml
    │       └── controllers.yaml
    │
    └── your_custom_pkg1/
        └── ...
```

ros2 lifecycle nodes
ros2 lifecycle get /bt_navigator
ros2 lifecycle get /planner_server
ros2 lifecycle get /controller_server
ros2 lifecycle get /behavior_server
ros2 lifecycle get /smoother_server

ros2 run tf2_ros tf2_echo map base_link
ros2 run tf2_ros tf2_echo odom base_link
ros2 topic echo --once /odom
ros2 topic hz /scan

ros2 topic echo --once /map
ros2 topic echo --once /global_costmap/costmap
ros2 topic echo --once /local_costmap/costmap

alias usb_cam='ros2 run usb_cam usb_cam_node_exe --ros-args -p video_device:="/dev/video1" -p pixel_format:="mjpeg2rgb" -p image_width:=640 -p image_height:=480 -p camera_name:="usb_cam" -p camera_info_url:="file:///root/.ros/camera_info/usb_cam.yaml" -r image_raw:=/camera/image_raw -r camera_info:=/camera/camera_info'

ros2 run usb_cam usb_cam_node_exe --ros-args -p video_device:="/dev/video1" -p pixel_format:="mjpeg2rgb" -p image_width:=640 -p image_height:=480 -p camera_name:="usb_cam" -p camera_info_url:="file:///root/.ros/camera_info/usb_cam.yaml" -r image_raw:=/camera/image_raw -r camera_info:=/camera/camera_info

## Setup After 5 April

### In Laptop

activate hot-spot

open two tmux windows A and B:

```bash
bash ./scripts/ros2env_tmux.sh
# then activate foxnode and discovery, respectively
```

and

```bash
bash ./scripts/g3nav2_tmux.sh
```

open foxglove app and connect to `ws://localhost:8765`

### In turtlebot Raspberry Pi

```bash
chesiumx
```

Test connectivity

```bash
talker
```

Then activate the drivers:

```bash
rosbu
```

### Run navigation

Activate the four commands in tmux B.
note: run the nav 2 startup command (down-left) after the cartographer output stablize (up-left)

after you can see the costmap layers in the RViz interface,
send the "start exploration" command in tmux A (down-right)

# ArUco Visual Servo Docking

Autonomous docking onto a 4×4 ArUco marker (ID 42, 16.5 cm) using the USB camera.
Runs entirely on the laptop — no Nav2 required.

## Prerequisites

- ROS 2 connection to robot established (see *Update/Connect to Hot-spot* above)
- `rosbu` running on the RPi (robot bringup — publishes `/cmd_vel`, `/odom`, etc.)

## 1. Build on the laptop

```bash
cd ~/nav_ws
colcon build --symlink-install --packages-select g3_visual_servo
source install/setup.bash
```

## 2. Start the USB camera

Run on the **laptop** (camera plugged into laptop USB):

```bash
ros2 run usb_cam usb_cam_node_exe --ros-args \
  -p video_device:="/dev/video1" \
  -p pixel_format:="mjpeg2rgb" \
  -p image_width:=640 \
  -p image_height:=480 \
  -p camera_name:="usb_cam" \
  -p camera_info_url:="file:///home/g3/camera_ws/src/calibration/usb_cam_calibration.yaml" \
  -r image_raw:=/usb_cam/image_raw \
  -r camera_info:=/usb_cam/camera_info
```

> If you see `unable to open camera calibration file`, that is fine — the node will still publish images; pose estimation just uses a fallback.

Verify the camera is streaming:

```bash
ros2 topic hz /usb_cam/image_raw
```

## 3. (Optional) Smoke-test cmd_vel

Before running the full docking node, verify the robot will actually move:

```bash
ros2 run g3_visual_servo cmd_vel_test
```

The robot should drive forward ~0.3 m then stop. If it does not move, check that `rosbu` is running on the RPi and the ROS 2 discovery server is configured correctly.

## 4. Run the docking node

```bash
ros2 run g3_visual_servo aruco_dock
```

State machine: `SEARCHING → LOCKING → TURN_TO_DOCK → DRIVE_TO_DOCK → DONE`

The node prints its current state and cmd_vel values to the terminal. It stops automatically when docking is complete.

## 5. (Optional) Visualise with Foxglove

```bash
foxnode   # alias for: ros2 launch foxglove_bridge foxglove_bridge_launch.xml
```

Open Foxglove → connect `ws://localhost:8765` → add an **Image** panel on `/aruco_debug/image_raw` to see the detected marker and overlay.

## Tunable constants ([aruco_dock_node.py](src/g3_visual_servo/g3_visual_servo/aruco_dock_node.py))

| Constant | Default | Meaning |
|---|---|---|
| `TARGET_MARKER` | `42` | ArUco ID to track |
| `MARKER_SIZE` | `0.165` m | Physical marker side length |
| `DOCK_DIST` | `0.50` m | Stop distance from marker |
| `MAX_LINEAR` | `0.12` m/s | Maximum forward speed |
| `MAX_ANGULAR` | `0.5` rad/s | Maximum turn speed |
| `LOCK_N` | `8` | Pose samples before committing |

---

# Camera USB

Turn it on using (no need to go into ssh mode)

ros2 run usb_cam usb_cam_node_exe --ros-args \
  -p video_device:="/dev/video1" \
  -p pixel_format:="mjpeg2rgb" \
  -p image_width:=640 \
  -p image_height:=480 \
  -p camera_name:="usb_cam" \
  -p camera_info_url:="file:///home/g3/camera_ws/src/calibration/usb_cam_calibration.yaml" \
  -r image_raw:=/usb_cam/image_raw \
  -r camera_info:=/usb_cam/camera_info

## Goal

ros2 action send_goal /dock_robot nav2_msgs/action/DockRobot "{ use_dock_id: false, dock_pose: { header: { frame_id: 'map' }, pose: { position: { x: 2.0, y: 0.0, z: 0.0 }, orientation: { w: 1.0 } } }, dock_type: 'aruco_dock', navigate_to_staging_pose: true }" --feedback
  
ros2 action send_goal /dock_robot nav2_msgs/action/DockRobot "{ use_dock_id: false, dock_pose: { header: { frame_id: 'map' }, pose: { position: { x: 2.0, y: 0.0, z: 0.0 }, orientation: { w: 1.0 } } }, dock_type: 'aruco_dock', navigate_to_staging_pose: false }" --feedback

ros2 launch g3gzsim nav2_docking_sim_test.launch.py \ headless:=True use_rviz:=False \ world:=$(ros2 pkg prefix g3gzsim)/share/g3gzsim/worlds/warehouse_world.sdf \ x_pose:=-7.0 y_pose:=-3.0

Terminal 1 — Nav2 + SLAM (no exploration):
  ros2 launch g3nav2 g3nav2_bringup_launch.py use_frontier:=False

  Terminal 2 — simple docking node:
  ros2 run g3_visual_servo simple_aruco_dock --ros-args -p image_topic:=/usb_cam/image_raw -p camera_info_topic:=/usb_cam/camera_info -p target_marker_id:=42 -p use_stamped_cmd_vel:=True

  Terminal 3 — Foxglove bridge:
  ros2 launch foxglove_bridge foxglove_bridge_launch.xml

  Terminal 4 — drive near the marker with teleop, then stop:
  ros2 run teleop_twist_keyboard teleop_twist_keyboard

  Terminal 5 — trigger docking:
  ros2 service call /simple_dock/start std_srvs/srv/Trigger

  Terminal 6 — watch debug:
  ros2 topic echo /aruco_debug --field data

---

# Nav2 Docking (branch: `feat/nav2-docking`)

Uses Nav2's `docking_server` with ArUco marker detection. The robot navigates to a staging point 0.7m in front of the marker, then the docking controller drives the final approach using live camera detection. Stops 30cm in front of the marker.

## How it works

1. `aruco_dock_pose_publisher` detects the ArUco marker and publishes its pose on `/detected_dock_pose`
2. You (or the FSM) send a `DockRobot` action goal with the approximate marker position in map frame
3. Nav2 navigates to a staging point 0.7m in front of the dock
4. The docking controller approaches using live camera detection
5. Robot stops when within `docking_threshold` of the target (30cm in front of marker)

## Configuration: where to change things

### ArUco marker size

The marker size affects solvePnP distance accuracy. **Wrong size = wrong distance = overshoot or undershoot.**

| File | Parameter | Default | When |
|---|---|---|---|
| `src/g3_visual_servo/launch/aruco_dock_hw_test.launch.py` | `marker_size` launch arg | `0.165` | Hardware (USB cam) |
| `src/g3gzsim/launch/nav2_docking_sim_test.launch.py` | `marker_size` launch arg | `0.18` | Simulation |

Override at launch: `marker_size:=0.067` (for 6.7cm marker)

### Camera topics

The pose publisher subscribes to camera image and camera_info. These differ between hardware and sim:

| Setup | `image_topic` | `camera_info_topic` | Set where |
|---|---|---|---|
| **Hardware (USB cam)** | `/usb_cam/image_raw` | `/usb_cam/camera_info` | `aruco_dock_hw_test.launch.py` |
| **Simulation (Gazebo)** | `/camera/image_raw` | `/camera/camera_info` | `nav2_docking_sim_test.launch.py` |
| **RPi camera_ros** | `/camera/image_raw` | `/camera/camera_info` | Override via `--ros-args` |

To override at launch or CLI:
```bash
ros2 run g3_visual_servo aruco_dock_pose_publisher --ros-args \
  -p image_topic:=/your/image/topic \
  -p camera_info_topic:=/your/camera_info/topic
```

### Docking parameters

| Parameter | Sim | Hardware | File |
|---|---|---|---|
| `docking_threshold` | `0.30` | `0.15` | `g3gzsim/nav2/nav2_params.yaml` / `g3nav2/config/g3_nav2_params.yaml` |
| `dock_offset_z` (stop distance) | `0.30` | `0.30` | `aruco_dock_pose_publisher.py` param `dock_offset_z` |
| `staging_x_offset` | `-0.7` | `-0.7` | Nav2 params (staging = dock_pose + 0.7m back) |
| `filter_coef` | `0.3` | `0.3` | Nav2 params (EMA smoothing, higher = more responsive) |
| `v_linear_max` | `0.15` | `0.15` | Nav2 params (approach speed) |

### Camera calibration

**Critical for IRL.** Without correct intrinsics, solvePnP distances are wrong and the robot won't stop at the right place.

The USB cam needs a calibration file. Check it's being loaded:
```bash
ros2 topic echo /usb_cam/camera_info --once
```
Verify `k` has non-zero focal lengths (fx, fy) and the principal point (cx, cy) is roughly center of frame. If `d` is all zeros and `k` looks wrong, the camera is uncalibrated.

To calibrate:
```bash
ros2 run camera_calibration cameracalibrator \
  --size 8x6 --square 0.025 \
  --ros-args -r image:=/usb_cam/image_raw -r camera_info:=/usb_cam/camera_info
```

## Test in Simulation

```bash
# Build
colcon build --packages-select g3_mission_control g3_visual_servo g3gzsim g3g_frontier_exploration
source install/setup.bash

# Launch sim (headless, no FSM — manual dock test)
ros2 launch g3gzsim nav2_docking_sim_test.launch.py \
  headless:=True use_rviz:=False use_fsm:=false

# In another terminal — send dock goal (marker is at x=3.0 in square_room)
ros2 action send_goal /dock_robot nav2_msgs/action/DockRobot "{
  use_dock_id: false,
  dock_pose: {header: {frame_id: 'map'}, pose: {position: {x: 3.0, y: 0.0, z: 0.0}, orientation: {w: 1.0}}},
  dock_type: 'aruco_dock',
  navigate_to_staging_pose: true
}" --feedback
```

Expected output:
```
Successful navigation to staging pose
Successful initial dock detection
Made contact with dock
Docking was successful!
Goal finished with status: SUCCEEDED
```

## Test on Real Robot

**Pi** — only runs hardware drivers:
```bash
rosbu   # turtlebot3 bringup (motors, lidar, odom)
```

**Laptop** — runs everything else:

```bash
# Terminal 1: Nav2 + SLAM
ros2 launch g3nav2 g3nav2_bringup_launch.py use_frontier:=False

# Terminal 2: USB camera + ArUco pose publisher
ros2 launch g3_visual_servo aruco_dock_hw_test.launch.py

# Terminal 3: Foxglove (optional, for debug)
ros2 launch foxglove_bridge foxglove_bridge_launch.xml

# Terminal 4: Verify detection is working
ros2 topic echo /aruco_debug --field data
# Should show: d3d=X.XXX d2d=X.XXX x=... y=... z=...

# Terminal 5: Send dock goal
# Replace x/y with the marker's approximate position in the map frame
ros2 action send_goal /dock_robot nav2_msgs/action/DockRobot "{
  use_dock_id: false,
  dock_pose: {header: {frame_id: 'map'}, pose: {position: {x: 1.5, y: 0.0, z: 0.0}, orientation: {w: 1.0}}},
  dock_type: 'aruco_dock',
  navigate_to_staging_pose: true
}" --feedback
```

### Quick IRL checklist

1. Camera streaming? `ros2 topic hz /usb_cam/image_raw` (should be ~30Hz)
2. Camera calibrated? `ros2 topic echo /usb_cam/camera_info --once` (check K matrix has real values)
3. ArUco detected? `ros2 topic echo /aruco_debug --field data` (should show distances, not `NO_DETECTION`)
4. Marker size correct? Default is 16.5cm. Override: `marker_size:=0.067`
5. Robot can move? `ros2 topic echo /cmd_vel --once` after sending dock goal

## Debug topics

| Topic | Type | What it shows |
|---|---|---|
| `/aruco_debug` | `String` | Distance to marker, pose values, or `NO_DETECTION` |
| `/detected_dock_pose` | `PoseStamped` | Raw marker pose in camera frame (fed to docking_server) |
| `/filtered_dock_pose` | `PoseStamped` | Smoothed pose after docking_server's EMA filter |
| `/docking_trajectory` | | Planned docking path |
| `/mission_state` | `String` | FSM state (when using `nav2_mission_fsm`) |

## Fallback: Simple ArUco Docking (no Nav2)

If Nav2 docking doesn't work IRL, use `simple_aruco_dock` which bypasses the docking_server entirely:
 kbu0hobunch g3nav2 g3nav2_bringup_launch.py use_frontier:=False

# Terminal 2: Simple docking node
ros2 run g3_visual_servo simple_aruco_dock

# Terminal 3: Drive near the marker with teleop, then stop
ros2 run teleop_twist_keyboard teleop_twist_keyboard

# Terminal 4: Trigger docking
ros2 service call /simple_dock/start std_srvs/srv/Trigger

# Terminal 5: Watch debug
ros2 topic echo /aruco_debug --field data
```

---

# Full Mission Pipeline (Explore + Dock)

The full pipeline uses the **simple mission FSM** to coordinate frontier exploration and ArUco docking automatically. The flow is: explore the environment, detect a marker, stop exploring, dock onto the marker.

```
INIT → EXPLORE → DOCK → DONE
```

## What runs where

### Raspberry Pi (TurtleBot)

Only hardware drivers:

```bash
rosbu   # turtlebot3 bringup (motors, lidar, odom)
```

The camera is plugged into the **laptop** USB, not the Pi.

### Laptop

Everything else runs on the laptop. You need **6 terminals**:

```bash
# Terminal 1: Build
cd ~/nav_ws
git pull origin main
colcon build --symlink-install
source install/setup.bash

# Terminal 2: USB camera
ros2 run usb_cam usb_cam_node_exe --ros-args \
  -p video_device:="/dev/video1" \
  -p pixel_format:="mjpeg2rgb" \
  -p image_width:=640 \
  -p image_height:=480 \
  -p camera_name:="usb_cam" \
  -p camera_info_url:="file:///home/g3/camera_ws/src/calibration/usb_cam_calibration.yaml" \
  -r image_raw:=/camera/image_raw \
  -r camera_info:=/camera/camera_info

# Terminal 3: Nav2 + SLAM
ros2 launch g3nav2 g3nav2_bringup_launch.py

# Terminal 4: Frontier explorer
ros2 run g3g_frontier_exploration frontier_explorer

# Terminal 5: ArUco dock node (passive scanning + docking)
ros2 run g3_visual_servo simple_aruco_dock

# Terminal 6: Mission FSM (orchestrates explore → dock)
ros2 run g3_mission_control simple_mission_fsm
```

Once Terminal 6 starts, the FSM will:
1. Wait for the explorer and dock services to come online
2. Enable frontier exploration automatically
3. Watch for marker 42 detection (passive scanning by the dock node)
4. When marker is seen: stop exploration, start docking approach
5. Dock completes: post-turn (parallel to wall) + post-shift (align camera)

## Monitoring

```bash
# FSM state (INIT/EXPLORE/DOCK/DONE)
ros2 topic echo /mission_state

# Docking debug (distance, bearing, normal, commands)
ros2 topic echo /aruco_debug --field data

# Marker detection
ros2 topic echo /aruco_dock/marker_visible
ros2 topic echo /aruco_dock/marker_distance

# Docking completion
ros2 topic echo /aruco_dock/done

# Foxglove (optional)
ros2 launch foxglove_bridge foxglove_bridge_launch.xml
# Connect at ws://localhost:8765, add Image panel on /aruco_debug/image_raw/compressed
```

## Testing docking in isolation (no Nav2 or explorer needed)

```bash
# Terminal 1: USB camera (same command as above)
# Terminal 2: Dock node
ros2 run g3_visual_servo simple_aruco_dock

# Terminal 3: Trigger docking manually
ros2 service call /aruco_dock/dock_to_a std_srvs/srv/Trigger

# Watch debug
ros2 topic echo /aruco_debug --field data

# Abort docking
ros2 service call /simple_dock/stop std_srvs/srv/Trigger
```

## Docking parameters (simple_aruco_dock)

| Parameter | Default | Meaning |
|---|---|---|
| `target_marker_id` | `42` | ArUco marker ID to track |
| `marker_size` | `0.067` m | Physical marker side length |
| `dock_distance` | `0.30` m | Stop distance from marker |
| `max_linear` | `0.02` m/s | Max approach speed |
| `max_angular` | `0.05` rad/s | Max turn speed during approach |
| `camera_forward_offset` | `0.08` m | Distance from robot pivot to camera |
| `final_heading_offset_deg` | `-90.0` | Post-dock turn target (-90 = wall on left, 90 = wall on right) |
| `approach_timeout` | `300.0` s | Max time for docking approach |

Override at launch:
```bash
ros2 run g3_visual_servo simple_aruco_dock --ros-args \
  -p marker_size:=0.165 \
  -p dock_distance:=0.25 \
  -p final_heading_offset_deg:=90.0
```

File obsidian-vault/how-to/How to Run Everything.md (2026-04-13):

# How to Run Everything

## 1. Docker Development Setup

### First Time
```bash
git clone git@github.com:Chesium/r2auto_nav_CDE2310.git -b jazzystack ~/nav_ws
cd ~/nav_ws
docker compose build
cp docker/ros_network.env.example docker/ros_network.env
```

### Start Container (Ubuntu)
```bash
xhost +local:docker
docker compose -f docker-compose.linux-host.yml up -d
docker compose -f docker-compose.linux-host.yml exec dev bash
```

### Start Container (WSL2)
```bash
docker compose -f docker-compose.yml -f docker-compose.wslg.yml up -d
docker compose -f docker-compose.yml -f docker-compose.wslg.yml exec dev bash
```

### Build Inside Container
```bash
cd ~/nav_ws
colcon build --symlink-install
source install/setup.bash   # or: roset
```

---

## 2. Simulation

### Full Stack (Exploration + Navigation)
```bash
colcon build && roset && ros2 launch g3gzsim nav2full_test_launch.py
```

Then in another terminal, start exploration:
```bash
ros2 service call /exploration/set_enabled std_srvs/srv/SetBool "{data: true}"
```

### Docking Test
```bash
ros2 launch g3gzsim nav2_docking_sim_test.launch.py headless:=False
```

Trigger docking manually:
```bash
ros2 action send_goal /dock_robot nav2_msgs/action/DockRobot "{
  use_dock_id: false,
  dock_pose: {header: {frame_id: 'map'}, 
    pose: {position: {x: 2.0, y: 0.0, z: 0.0}, orientation: {w: 1.0}}},
  dock_type: 'aruco_dock',
  navigate_to_staging_pose: true
}" --feedback
```

### Headless (No GUI)
```bash
ros2 launch g3gzsim nav2_docking_sim_test.launch.py headless:=True use_rviz:=False
```

### Teleop in Simulation
```bash
ros2 run turtlebot3_teleop teleop_keyboard
```

---

## 3. Real Hardware

### Step 1: Network Setup
1. Activate phone hotspot
2. Connect RPi and laptop to same hotspot
3. Edit `docker/ros_network.env` with laptop's IP
4. Edit `~/.bashrc` on BOTH RPi and laptop:
```bash
export RMW_IMPLEMENTATION=rmw_fastrtps_cpp
export ROS_SUPER_CLIENT=TRUE
export ROS_DISCOVERY_SERVER=<LAPTOP_IP>:11811
export ROS_DOMAIN_ID=32
```
5. Source bashrc on both: `source ~/.bashrc`
6. Restart ROS daemon on both: `ros2 daemon stop && ros2 daemon start`

### Step 2: Start Robot
```bash
# On RPi:
rosbu
```

### Step 3: Verify Connectivity
```bash
# On RPi:
ros2 run demo_nodes_cpp talker

# On Laptop (should see /chatter):
ros2 topic list
```

### Step 4: Start SLAM
```bash
# On Laptop:
slam use_rviz:=false
# (alias for: ros2 launch turtlebot3_cartographer cartographer.launch.py)
```

### Step 5: Start Nav2
```bash
ros2 launch g3nav2 g3nav2_bringup_launch.py
```

### Step 6: Start Camera
```bash
# On Laptop (USB camera plugged in):
ros2 run usb_cam usb_cam_node_exe --ros-args \
  -p video_device:="/dev/video1" \
  -p pixel_format:="mjpeg2rgb" \
  -p image_width:=640 \
  -p image_height:=480 \
  -p camera_name:="usb_cam" \
  -p camera_info_url:="file:///home/g3/camera_ws/src/calibration/usb_cam_calibration.yaml" \
  -r image_raw:=/usb_cam/image_raw \
  -r camera_info:=/usb_cam/camera_info
```

### Step 7: Start Exploration
```bash
ros2 service call /exploration/set_enabled std_srvs/srv/SetBool "{data: true}"
```

---

## 4. Monitoring with Foxglove

```bash
# Start bridge:
ros2 launch foxglove_bridge foxglove_bridge_launch.xml
# (or alias: foxnode)
```

Open Foxglove Studio -> Connect `ws://localhost:8765`

Useful panels:
- **Image** on `/aruco_debug/image_raw` - ArUco detection overlay
- **Image** on `/receptacle/annotated` - Hough circle overlay
- **Map** on `/map` - SLAM map
- **Text** on `/mission_state` - Current FSM state
- **Text** on `/launcher_status` - Ball launcher state

---

## 5. Useful Debug Commands

```bash
# See all topics
ros2 topic list

# Check camera is publishing
ros2 topic hz /camera/image_raw

# Check SLAM is working
ros2 topic hz /map

# See current mission state
ros2 topic echo /mission_state

# See launcher status
ros2 topic echo /launcher_status

# Check TF tree
ros2 run tf2_ros tf2_echo map base_link

# Check Nav2 lifecycle states
ros2 lifecycle get /bt_navigator
ros2 lifecycle get /planner_server
ros2 lifecycle get /controller_server

# List all nodes
ros2 node list

# Manual teleop
ros2 run turtlebot3_teleop teleop_keyboard
```

---

**See also:** [[Package Index]], [[Architecture Overview]]

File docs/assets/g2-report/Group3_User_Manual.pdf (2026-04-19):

# CDE2310 User Manual

# 1. System Overview

The system is an Autonomous Mobile Robot (AMR) built on the TurtleBot3 Burger platform for warehouse intralogistics simulation. It autonomously explores an unknown environment, detects stations using fiducial markers, and delivers payloads (ping-pong balls) into receptacles.

### The system integrates:

### - Navigation (Nav2 + SLAM/exploration) - Perception (ArUco docking + vision-based alignment) - Actuation (servo-driven launcher)

### Two delivery modes are implemented:

### - Station A: deterministic timed firing - Station B: event-triggered firing

# 2. Hardware Configuration

## 2.1 Mobile Base

Platform | TurtleBot3 Burger
Drive Type | Differential drive
Dimensions (L × W × H) | 225mm x 180mm x 230mm
Weight | 1469 g
Center of Gravity | x: 38.6, y: 31.1, z: 56.1

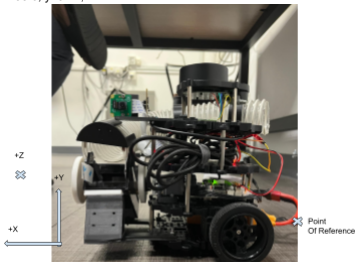
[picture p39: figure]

Max linear velocity | 0.22 m/s
Max rotational velocity | 2.84 rad/s (162.72 deg/s)
Sensors | LDS-02 LiDAR, 3-axis Gyroscope, 3-Axis Accelerometer
Power Supply | LiPo battery (~11.1V, 1800 mAh)

Max Operating Time | 1.5 - 2h
Charging time | 2h

## 2.2 Compute & Control

Main Computer | Raspberry Pi 4B
Motor Controller | OpenCR1.0
Communication | ROS 2 DDS

## 2.3 Perception Sensors

Front Camera (USB Camera) | ● Purpose: ArUco marker detection & docking ● Output: Station pose (PnP-based estimation)
Side Camera (Raspberry Pi Camera v2.1) | ● Purpose: Fine alignment & trigger detection ● Methods: - Hough Circle detection (receptacle) - HSV thresholding (Station B LED trigger)

## 2.4 Payload Delivery Mechanism

Launcher System | ● Type: Cam-based spring-loaded mechanism ● Actuation: UART-controlled servo motor (DC mode) ● Function: Converts rotational motion into impulse for ball launching
Feeding Mechanism | ● Type: Gravity-fed tube ● Capacity: 9 ping pong balls ● Function: Passive sequential reloading

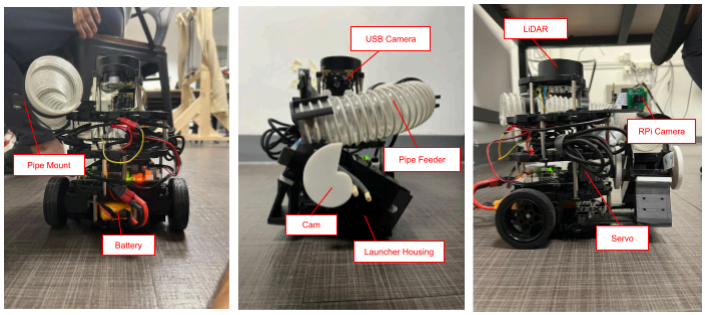
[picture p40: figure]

# 3. Technical Guide

## Setup

1. Turn on the robot switch.
2. Load 9 ping pong balls into the feeder.
3. Place the TurtleBot3 at the start line.

## Launch

Run the command on the laptop terminal:

start

The robot begins moving autonomously.

## Phase 1: Exploration

The robot navigates the maze autonomously using frontier exploration, systematically visiting unexplored regions while avoiding obstacles. As it moves, Cartographer builds a 2D occupancy map via SLAM, which can be monitored in real time through Foxglove or RViz.

Exploration continues until a station is detected.

## Phase 2: Docking

When the robot's front camera detects an ArUco marker above a station receptacle, it interrupts exploration and begins the docking approach. The robot advances toward the marker in short incremental steps, pausing between each step to re-read the marker's pose and correct its bearing. It aims to arrive approximately 30cm from the marker, aligned as perpendicular to the wall as possible.

Once within docking range, the robot rotates so that its side-mounted launcher faces the receptacle. The side camera then takes over, detecting the circular opening of the receptacle using Hough circle detection. The robot adjusts forward or backwards until the receptacle opening is centred in the camera frame.

## Phase 3: Firing

The firing sequence depends on which station was detected.

Station A (static receptacle): The receptacle is fixed in place. Once aligned, the launcher immediately fires a ball, waits 7 seconds, then fires a second ball and waits 3 seconds, then fires the third ball.

Station B (moving receptacle): The receptacle has a tin can that travels back and forth on a motorised rail. A blue LED inside the tin can signals its presence behind the cutout opening. After aligning to the wooden receptacle frame, the robot watches for blue light through the opening using the side camera. When the blue LED is detected and confirmed over several consecutive frames, the launcher fires. The robot then waits for the tin can to return on its next pass before firing the second and third balls.

If a station is left, the robot will continue exploring to find the next station. If both stations are complete, the mission ends.

# 4. Acceptable Defect Log

Part | Acceptable Defect
Cam and shaft | ● Shaft not able to be fully hammered into cam
Feeder pipe | ● Pipe blocker fastened using superglue ● One feeder mount is not in full contact with the waffle plate ● Edges are rough
LiDAR | ● LiDAR supports are slightly bent
Launcher housing | ● Launcher mount has warped bottom due to excess heat during 3D printing ● There is some tape inside launcher
Dowels | ● Edges of dowels are rough
Rpi Camera Mount | ● Rpi camera edges are not fully within the mount’s edges
Selected nuts and bolts | ● Launcher bolts have no nuts due to inaccessible locations. Instead they are screwed in ● Some nuts are fully tightened but are not seated flush against bolt due to waffle plate thickness
All electronic components | ● Open and vulnerable to wear and tear ● Unorganised wires

# 5. Factory Acceptance Test

# CDE2310 AMR FAT

Mechanical | Task | Check
| OpenCR riveted down in the correct orientation | ✓
| Raspberry Pi bolted down | ✓
| Front and side cameras are mounted and active | ✓
| Shaft and Cam are mated tightly | ✓
| No loose screws, nuts or bolts present | ✓
| Servo is mounted | ✓
| Feeder is oiled, mounted and not blocking LiDAR | ✓
Electrical | The battery is fully charged, working and plugged into OpenCR | ✓
| OpenCR boots up normally and sings a tune | ✓
| Servo control board, USB Camera, LiDAR, and OpenCR plugged into RPi USB ports and working | ✓
| Servo control board pins powered by RPi power pins | ✓
| OpenCR power and ground pins connected to RPi power and ground pins | ✓
| Wires and cables are undamaged and unexposed | ✓

Software | Laptop can SSH into Turtlebot RPi | ✓
| Laptop and RPi are on the same ROS Discovery Network | ✓
| Cartographer, Nav2, Frontier Exploration Nodes are working | ✓
| Foxglove Visualiser is working | ✓
| Rosbu is activated | ✓

# 6. Maintenance and Part Replacement Log

Components | Description
Raspberry Pi 4B 1 | Plugged 5V pin of OpenCR into GND pin of RPi and GND pin of OpenCR into 5V pin of RPi, damaged the RPi with reverse voltage. Replaced
Raspberry Pi 4B 2 | Dropped nut on top of live RPi while unscrewing a bolt, possibly causing the RPi to short-circuit, resulting in a permanent undervoltage characterised by a persistent red light with regular flashing green lights. Furthermore, running computationally intensive tasks on the RPi like Hough circle detection, might have caused the RPi to overheat and accumulate damage. Replaced.
OpenCR 1.0 | Possibly the same reason as RPi, due to doing mechanical work on live electronics, the OpenCR status light is not working, and is unable to connect to RPi. Replaced.
Servo Wires | Servo jumper wires keep disconnecting from RPi power pins, replaced with different wires
Launcher, Pipe Feeder and Camera Mount | Positions of the pipe, Launcher mechanism and camera mount keep adjusting in order to accommodate new requirements to launcher angle, gravity feeding and camera alignment
Cam and Shaft | The cam and shaft are repeatedly reprinted and assembled due to servo’s inability to rotate clockwise (which unscrews the servo disc), strength requirements, tight fit between cam and shaft and more. Prototyped cam and shaft through multiple iterations. Reprogrammed the servo to only turn clockwise when launching and initialising, and hammered the shaft and cam together tightly to ensure a friction fit.

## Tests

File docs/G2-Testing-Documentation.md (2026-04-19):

# Testing Documentation

[Home](../README.md)

This section summarises the main tests carried out while preparing for the graded run. The tests focused on launcher reliability, receptacle alignment, and early validation of the navigation and exploration stack.

## Launcher and Mechanical

The launcher subsystem required extensive empirical testing because the physical behaviour of the servo and cam mechanism did not always match the expected motion from the documentation. In particular, while the hardware nominally supported counterclockwise motion in servo mode, the final design required continuous DC-mode rotation, which introduced practical constraints and forced a redesign of the cam geometry.

### 1. Proof-of-Concept Test

**Aim:** Verify that the cam-based mechanism could launch ping-pong balls over a distance of approximately 20-30 cm.

**Outcome:** The mechanism successfully launched the balls, confirming that the concept was viable.

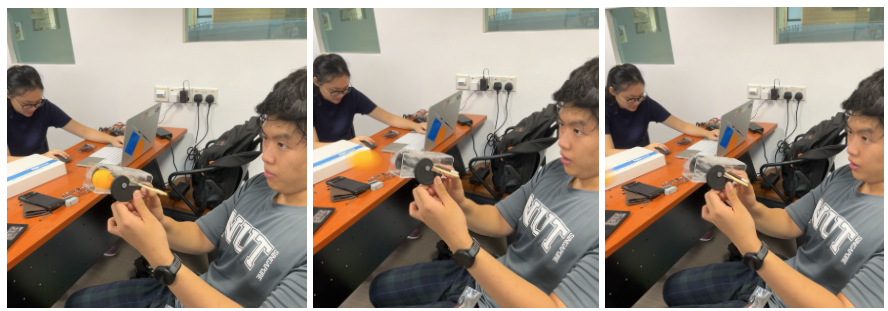
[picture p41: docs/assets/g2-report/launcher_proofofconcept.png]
launch15


### 2. Isolated Test with Tin

**Aim:** Evaluate whether the launcher could consistently score into a stationary tin receptacle.

**Outcome:** The system was able to score, but the firing result was inconsistent.

**Action:** A follow-up diagnostic test was conducted to identify the sources of inconsistency before repeating the isolated firing test.

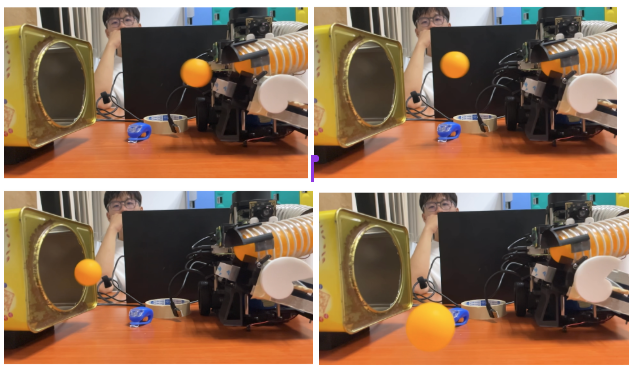
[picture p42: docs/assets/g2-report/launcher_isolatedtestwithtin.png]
launch10


### 3. Inconsistency Check Test

**Aim:** Identify the causes of inconsistent launcher behaviour.

**Outcome:** Three primary issues were identified:

- Ball position within the launcher was not repeatable.
- The two cams had uneven edges, causing one side to release before the other and driving the striker at an angle.
- Tape inside the launcher interfered with striker motion and introduced additional variation in shot direction.

**Action:** The team added tape to stabilise ball positioning, filed one cam edge to better match the other, and repositioned the internal tape to keep it outside the striker path.

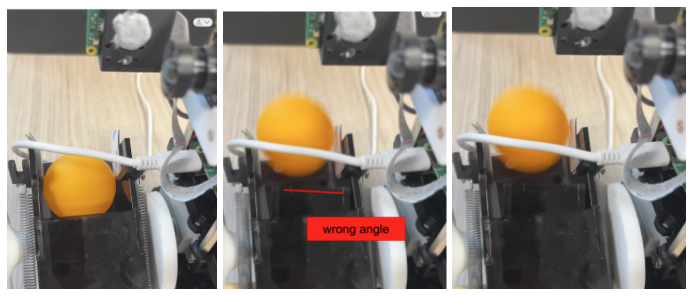
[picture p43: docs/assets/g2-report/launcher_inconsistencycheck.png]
launch7


### 4. Station A Test

**Aim:** Evaluate launcher performance using the actual maze tin geometry for Station A.

**Outcome:** The receptacle height in the real setup was higher than assumed during the isolated tin test, so the ball repeatedly struck the lower rim.

**Action:** The launcher angle was adjusted and the earlier firing tests were repeated with the revised geometry.

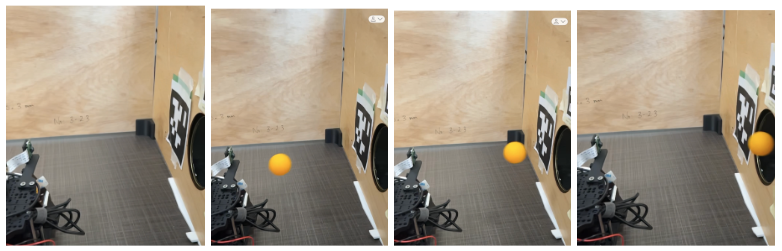
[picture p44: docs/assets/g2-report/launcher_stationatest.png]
dock1


<p align="center">Fig: Station A launcher test before and after angle adjustment</p><br>

### 5. Alignment with RPi Camera Integration Test

**Aim:** Verify that the launcher remained accurate when alignment was driven by the RPi camera and Hough-based receptacle detection.

**Outcome:** The test was successful. The cam position was adjusted until the launcher remained accurate under vision-guided alignment.

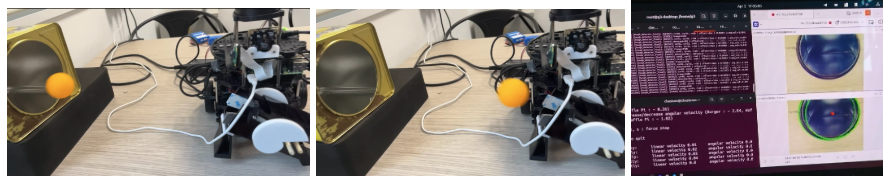
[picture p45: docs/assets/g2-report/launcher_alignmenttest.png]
launch13


## Receptacle Alignment

### Station A

**Test A-1: Hough Circle Parameter Calibration**

The objective was to identify suitable values for `MIN_R`, `MAX_R`, and `PARAM2` over the required stand-off range of 22-38 cm. The robot was positioned at measured distances within this range while the aligner node was executed. Circle radii and detection quality were monitored through the annotated image feed, and the parameters were tuned iteratively until stable detection was achieved. The final settings, `MIN_R = 80`, `MAX_R = 150`, and `PARAM2 = 45`, provided reliable receptacle detection while suppressing false circles from the acrylic maze walls.

**Test A-2: P-Controller Convergence**

The robot was placed approximately 10 cm out of alignment before the Station A aligner was activated. The time required to reach the `ALIGNED` condition and satisfy the stable-frame threshold was recorded. The controller converged in approximately 2 seconds at a stand-off distance of 30 cm with no visible oscillation.

### Station B

**Test B-1: HSV Threshold Calibration**

The objective was to calibrate HSV thresholds for blue LED detection. The LED target was powered while the side camera observed the moving receptacle. Hue, saturation, and value limits were adjusted until the detected LED area exceeded `200 px^2` when visible and remained below `20 px^2` when obscured. The final thresholds, `H[100-130]`, `S[180-255]`, and `V[200-255]`, produced clean segmentation. Visible LED area typically ranged from `400-800 px^2`, while obscured states remained below `10 px^2`.

**Test B-2: Cutout Alignment Validation**

The objective was to confirm that Phase 1 alignment reliably targeted the circular cutout rather than the moving receptacle itself. With the receptacle placed at multiple positions, the aligner was run repeatedly and consistently locked onto the cutout centroid. Hough detection remained reliable across the 22-38 cm operating range, and alignment was typically achieved within five stable frames.

**Test B-3: Rising-Edge Trigger Validation**

The receptacle was moved manually past the cutout while launch events were monitored. With `LED_CONFIRM_FRAMES = 30`, the debounce logic prevented double-triggering, and each pass of the receptacle generated exactly one fire event.

## Navigation and Exploration Test in Simulation

Before committing fully to hardware tests, the team performed an early logic validation of the frontier exploration node in Gazebo using the `simple_colored_warehouse` environment. This helped identify several core issues, including frontier detection outside wall boundaries and an infinite-loop behaviour that was later mitigated by the addition of the information-gain check.

Although the simulator was useful for early debugging, the team transitioned quickly to real-hardware testing because of the large gap between the simulated and physical environments. During these tests, it was also observed that node processes launched by Cartographer and Nav2 could remain alive after `Ctrl-C`, which sometimes interfered with subsequent runs. To streamline later tests, the team created one-line cleanup commands and shell aliases to terminate residual processes reliably.

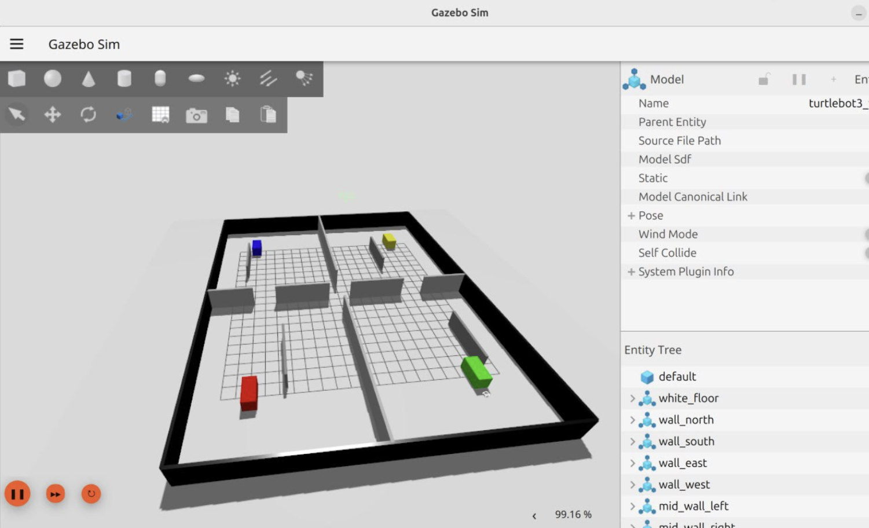
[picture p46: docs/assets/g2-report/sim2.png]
sim2


<p align="center">Fig: Gazebo environment used for early exploration testing</p><br>

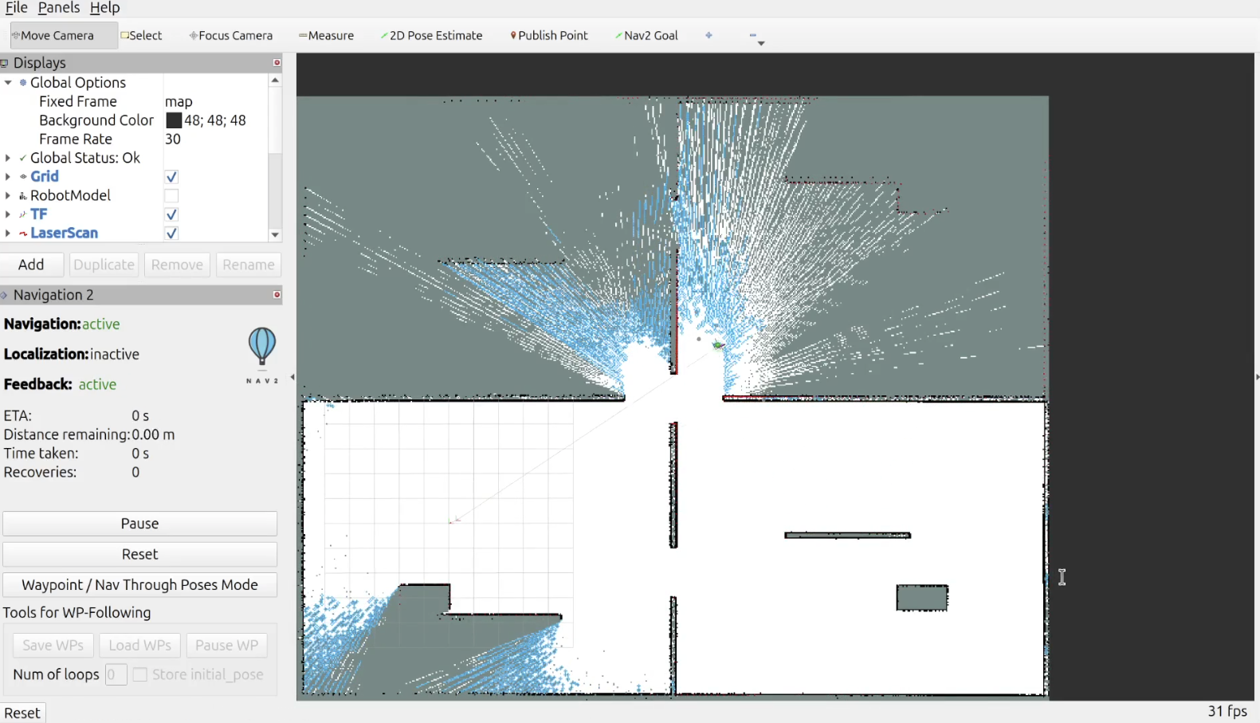
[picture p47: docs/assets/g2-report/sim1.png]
sim1


<p align="center">Fig: RViz view showing frontiers detected during the initial simulation tests</p><br>

## Camera and Servo Integration Issues

Integration testing also highlighted several practical issues around power and configuration. The launcher was tested with a bench power supply to estimate current requirements and validate the electrical budget. This confirmed that the Raspberry Pi power pins could support the servo current draw of approximately `300 mA`, removing the need for a separate `5V` DC-DC converter in the final configuration.

These tests also reinforced the importance of checking parameter flags carefully before each run, as incorrect launch or runtime configuration could mask otherwise functional subsystem behaviour.

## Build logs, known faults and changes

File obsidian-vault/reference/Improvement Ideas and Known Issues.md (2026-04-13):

# Improvement Ideas and Known Issues

## Known Issues

### 1. `/cmd_vel` Ownership Conflict
**Problem:** Multiple nodes publish to `/cmd_vel` simultaneously:
- `station_a_aligner` publishes linear-only commands
- `mission_controller.offset_callback()` publishes angular-only commands
- `aruco_dock_node` publishes combined commands
- Nav2 controller publishes during navigation

**Impact:** During alignment, interleaved messages mean some frames have linear but no angular, and vice versa. The "last publisher wins" on each frame.

**Fix:** Create a single velocity mux node that combines linear and angular from different sources. Or have one node aggregate both alignment axes.

### 2. Blocking `time.sleep()` in `ball_launcher_node.py`
**Problem:** The fire sequence uses `time.sleep(0.1)` on the ROS thread after setting `status = 'complete'`.

**Impact:** Minimal since it's only 100ms, but the main fire loop correctly runs in a daemon thread. The post-fire sleep on line 224 is fine.

### 3. Station B Aligner Missing
**Problem:** `station_b_aligner.py` exists but wasn't read - it likely needs different parameters since Station B has a moving receptacle.

**Todo:** Verify Station B aligner handles the moving target differently (probably needs prediction or faster loop).

### 4. `mission_controller_2.0.py` and `mission_controller_stub.py` Unused
**Problem:** These files are in the package but appear to be old versions. They add confusion.

**Fix:** Archive or remove if no longer needed.

### 5. Sim vs Hardware Camera Topic Mismatch
**Problem:** 
- Hardware camera: `/usb_cam/image_raw`
- Sim camera: `/camera/image_raw`

Nodes hardcode one or the other. `aruco_dock_node.py` uses `/usb_cam/*`, `aruco_dock_pose_publisher.py` parameterizes it.

**Fix:** Always parameterize camera topics (the new pose publisher does this correctly).

---

## Architecture Improvements

### 1. Unify Docking Approach
Currently two parallel docking systems:
- **Legacy:** `aruco_dock_node.py` (custom PI control)
- **New:** `aruco_dock_pose_publisher.py` + Nav2 docking_server

**Recommendation:** Commit fully to Nav2 docking. The pose publisher is cleaner architecture (separation of concerns). Phase out the legacy node once Nav2 docking is proven reliable.

### 2. Make `g3_receptacle_aligner` a Proper ROS2 Package
Currently standalone scripts, not a `colcon` package. No `setup.py`, no `package.xml`.

**Fix:** Create proper package structure so it can be built, launched, and parameterized properly.

### 3. Add Health Monitoring
No node monitors overall system health. If SLAM dies or Nav2 crashes, the mission controller doesn't know.

**Idea:** Add a watchdog node that monitors critical topic rates (`/map`, `/scan`, `/odom`) and triggers recovery or alerts.

### 4. Parameter Externalization
Many parameters are hardcoded constants (PID gains, Hough circle params, timing delays). 

**Fix:** Declare all tunable values as ROS parameters so they can be set from launch files or YAML configs without code changes.

---

## Performance Tuning Ideas

### Frontier Exploration
- **Increase `planning_rate_hz`** from 1.0 to 2.0 for faster replanning
- **Decrease `completion_patience_cycles`** if exploration ends too late
- **Tune `min_goal_distance`** based on room size

### ArUco Docking
- **Increase `EMA_ALPHA`** for faster response (but more noise)
- **Decrease `DOCK_DIST`** to get closer to station
- **Tune PI gains** if robot oscillates or approaches too slowly

### Ball Launcher Timing
- **Measure actual servo response time** and adjust `fire_duration`
- **Tune station_a_delays** based on actual receptacle timing

---

## Testing Checklist

- [ ] Sim: Full exploration completes without getting stuck
- [ ] Sim: Robot reaches all frontiers before declaring complete
- [ ] Sim: Docking test reaches marker within tolerance
- [ ] Sim: Nav2 docking action succeeds end-to-end
- [ ] HW: Camera publishes at expected rate
- [ ] HW: ArUco detection works at various distances
- [ ] HW: Hough circle detection rejects false positives (acrylic)
- [ ] HW: Ball launcher fires 3 balls reliably
- [ ] HW: Full mission completes (explore -> navigate -> align -> fire -> repeat)
- [ ] HW: Robot recovers from navigation failures

---

**See also:** [[Architecture Overview]], [[Package Index]]

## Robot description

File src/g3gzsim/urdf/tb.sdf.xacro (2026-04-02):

<?xml version="1.0"?>
<sdf version="1.6" xmlns:xacro="http://www.ros.org/wiki/xacro">
    <xacro:arg name="namespace" default=""/>

    <model name="turtlebot3_waffle"> 
      <pose>0.0 0.0 0.0 0.0 0.0 0.0</pose>

      <link name="base_footprint"/>

      <link name="base_link">

        <inertial>
          <pose>-0.064 0 0.048 0 0 0</pose>
          <inertia>
            <ixx>0.001</ixx>
            <ixy>0.000</ixy>
            <ixz>0.000</ixz>
            <iyy>0.001</iyy>
            <iyz>0.000</iyz>
            <izz>0.001</izz>
          </inertia>
          <mass>1.0</mass>
        </inertial>

        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
      </link>

      <link name="imu_link">
        <sensor name="tb3_imu" type="imu">
          <always_on>true</always_on>
          <update_rate>200</update_rate>
          <topic>$(arg namespace)/imu</topic>
          <gz_frame_id>imu_link</gz_frame_id>
          <imu>
            <angular_velocity>
              <x>
                <noise type="gaussian">
                  <mean>0.0</mean>
                  <stddev>2e-4</stddev>
                </noise>
              </x>
              <y>
                <noise type="gaussian">
                  <mean>0.0</mean>
                  <stddev>2e-4</stddev>
                </noise>
              </y>
              <z>
                <noise type="gaussian">
                  <mean>0.0</mean>
                  <stddev>2e-4</stddev>
                </noise>
              </z>
            </angular_velocity>
            <linear_acceleration>
              <x>
                <noise type="gaussian">
                  <mean>0.0</mean>
                  <stddev>1.7e-2</stddev>
                </noise>
              </x>
              <y>
                <noise type="gaussian">
                  <mean>0.0</mean>
                  <stddev>1.7e-2</stddev>
                </noise>
              </y>
              <z>
                <noise type="gaussian">
                  <mean>0.0</mean>
                  <stddev>1.7e-2</stddev>
                </noise>
              </z>
            </linear_acceleration>
          </imu>
        </sensor>
      </link>

      <link name="base_scan">
        <inertial>
          <pose>-0.064 0 0.121 0 0 0</pose>
          <inertia>
            <ixx>0.001</ixx>
            <ixy>0.000</ixy>
            <ixz>0.000</ixz>
            <iyy>0.001</iyy>
            <iyz>0.000</iyz>
            <izz>0.001</izz>
          </inertia>
          <mass>0.125</mass>
        </inertial>

        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

        <sensor name="hls_lfcd_lds" type="gpu_lidar">
          <always_on>true</always_on>
          <visualize>true</visualize>
          <pose>-0.064 0 0.15 0 0 0</pose>
          <update_rate>5</update_rate>
          <topic>$(arg namespace)/scan</topic>
          <gz_frame_id>base_scan</gz_frame_id>
          <ray>
            <scan>
              <horizontal>
                <samples>360</samples>
                <resolution>1.000000</resolution>
                <min_angle>0.000000</min_angle>
                <max_angle>6.280000</max_angle>
              </horizontal>
            </scan>
            <range>
              <min>0.18</min>
              <max>7.0</max>
              <resolution>0.015000</resolution>
            </range>
            <noise>
              <type>gaussian</type>
              <mean>0.0</mean>
              <stddev>0.01</stddev>
            </noise>
          </ray>
        </sensor>
      </link>

      <link name="wheel_left_link">

        <inertial>
          <pose>0.0 0.144 0.023 -1.57 0 0</pose>
          <inertia>
            <ixx>0.001</ixx>
            <ixy>0.000</ixy>
            <ixz>0.000</ixz>
            <iyy>0.001</iyy>
            <iyz>0.000</iyz>
            <izz>0.001</izz>
          </inertia>
          <mass>0.1</mass>
        </inertial>

        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
      </link>

      <link name="wheel_right_link">

        <inertial>
          <pose>0.0 -0.144 0.023 -1.57 0 0</pose>
          <inertia>
            <ixx>0.001</ixx>
            <ixy>0.000</ixy>
            <ixz>0.000</ixz>
            <iyy>0.001</iyy>
            <iyz>0.000</iyz>
            <izz>0.001</izz>
          </inertia>
          <mass>0.1</mass>
        </inertial>
      
        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
      </link>

      <link name='caster_back_right_link'>
        <pose>-0.177 -0.064 -0.004 0 0 0</pose>
        <inertial>
          <mass>0.001</mass>
          <inertia>
            <ixx>0.00001</ixx>
            <ixy>0.000</ixy>
            <ixz>0.000</ixz>
            <iyy>0.00001</iyy>
            <iyz>0.000</iyz>
            <izz>0.00001</izz>
          </inertia>
        </inertial>
        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
      </link>

      <link name='caster_back_left_link'>
        <pose>-0.177 0.064 -0.004 0 0 0</pose>
        <inertial>
          <mass>0.001</mass>
          <inertia>
            <ixx>0.00001</ixx>
            <ixy>0.000</ixy>
            <ixz>0.000</ixz>
            <iyy>0.00001</iyy>
            <iyz>0.000</iyz>
            <izz>0.00001</izz>
          </inertia>
        </inertial>
        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
      </link>

      <link name="camera_link">
        <inertial>
          <pose>0.069 -0.047 0.107 0 0 0</pose>
          <inertia>
            <ixx>0.001</ixx>
            <ixy>0.000</ixy>
            <ixz>0.000</ixz>
            <iyy>0.001</iyy>
            <iyz>0.000</iyz>
            <izz>0.001</izz>
          </inertia>
          <mass>0.035</mass>
        </inertial>
        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

        <pose>0.069 -0.047 0.107 0 0 0</pose>

        <sensor name="intel_realsense_r200_depth" type="depth">
          <always_on>1</always_on>
          <update_rate>5</update_rate>
          <pose>0.064 -0.047 0.107 0 0 0</pose>
          <gz_frame_id>camera_depth_frame</gz_frame_id>
          <camera name="realsense_depth_camera">
            <horizontal_fov>1.047</horizontal_fov>
            <image>
              <width>320</width>
              <height>240</height>
            </image>
            <lens>
              <projection>
                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
                <tx>19.4</tx>
              </projection>
            </lens>
            <depth_camera>
              <clip>
                <near>0.001</near>
                <far>5.0</far>
              </clip>
            </depth_camera>
          </camera>
        </sensor>

        <sensor name="rgb_camera" type="camera">
          <always_on>1</always_on>
          <update_rate>30</update_rate>
          <pose>0.064 -0.047 0.107 0 0 0</pose>
          <topic>$(arg namespace)/camera/image_raw</topic>
          <gz_frame_id>camera_rgb_optical_frame</gz_frame_id>
          <camera name="rgb_camera">
            <horizontal_fov>1.047</horizontal_fov>
            <image>
              <width>640</width>
              <height>480</height>
              <format>R8G8B8</format>
            </image>
            <clip>
              <near>0.1</near>
              <far>100.0</far>
            </clip>
          </camera>
        </sensor>
      </link>

      <joint name="base_joint" type="fixed">
        <parent>base_footprint</parent>
        <child>base_link</child>
        <pose>0.0 0.0 0.010 0 0 0</pose>
      </joint>

      <joint name="wheel_left_joint" type="revolute">
        <parent>base_link</parent>
        <child>wheel_left_link</child>
        <pose>0.0 0.144 0.023 -1.57 0 0</pose>
        <axis>
          <xyz>0 0 1</xyz>
        </axis>
      </joint>

      <joint name="wheel_right_joint" type="revolute">
        <parent>base_link</parent>
        <child>wheel_right_link</child>
        <pose>0.0 -0.144 0.023 -1.57 0 0</pose>
        <axis>
          <xyz>0 0 1</xyz>
        </axis>
      </joint>

      <joint name='caster_back_right_joint' type='ball'>
        <parent>base_link</parent>
        <child>caster_back_right_link</child>
      </joint>

      <joint name='caster_back_left_joint' type='ball'>
        <parent>base_link</parent>
        <child>caster_back_left_link</child>
      </joint>
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

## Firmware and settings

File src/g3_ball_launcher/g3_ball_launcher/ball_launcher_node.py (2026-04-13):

#!/usr/bin/env python3
import threading
import time

import serial
import rclpy
from rclpy.node import Node
from std_msgs.msg import String
from std_srvs.srv import Trigger

# Import the UART servo SDK (bundled inside this package under uart_sdk/)
from .uart_sdk.uart_servo import UartServoManager
from .uart_sdk.data_table import MOTOR_MODE_DC, MOTOR_MODE_SERVO, DC_DIR_CW, DC_DIR_CCW

# --- Hardware config ---
SERVO_PORT = '/dev/ttyUSB0'  # USB serial port the servo is connected to
SERVO_BAUD = 115200          # Must match servo's configured baud rate
SERVO_ID = 1                 # ID of the launcher servo on the bus
FIRE_DURATION = 2.2          # How long (seconds) to spin the motor per ball
HOME_POSITION = 2048         # Midpoint (0-4095) to return to after each shot
INIT_POSITION = 4000         # Position to move to on startup before switching to DC mode


class BallLauncherNode(Node):
    def __init__(self):
        super().__init__('ball_launcher')

        # Tracks current launcher state. Mission controller reads this via /launcher_status.
        # Valid values: 'idle' | 'firing' | 'complete' | 'error'
        self.status = 'error'

        # Lock prevents a second fire command from interfering while _fire_thread is running
        self._lock = threading.Lock()
        self._serial_lock = threading.Lock()
        self._stop_requested = threading.Event()

        self.uart = None
        self.uservo = None

        self.declare_parameter('servo_port', SERVO_PORT)
        self.declare_parameter('servo_baud', SERVO_BAUD)
        self.declare_parameter('servo_id', SERVO_ID)
        self.declare_parameter('fire_duration', FIRE_DURATION)

        self.servo_port = str(self.get_parameter('servo_port').value)
        self.servo_baud = int(self.get_parameter('servo_baud').value)
        self.servo_id = int(self.get_parameter('servo_id').value)
        self.fire_duration = float(self.get_parameter('fire_duration').value)

        # --- ROS interfaces ---
        # Publishes 'idle'/'firing'/'complete' so mission controller knows launcher state
        self.status_pub = self.create_publisher(String, '/launcher_status', 10)
        self.create_service(Trigger, '/fire_launcher', self.handle_fire_request)
        self.create_service(Trigger, '/stop_launcher', self.handle_stop_request)
        # Broadcast status at 10 Hz so mission controller always has a fresh reading
        self.create_timer(0.1, self.publish_status)
        # Retry serial connection in the background so a replugged device can recover
        self.create_timer(1.0, self._ensure_servo_connection)

        self._connect_servo()

        self.get_logger().info('Ball launcher node ready.')

    def _close_uart(self):
        if self.uart is None:
            return

        try:
            if self.uart.is_open:
                self.uart.close()
        except serial.SerialException:
            pass

        self.uart = None
        self.uservo = None

    def _handle_serial_failure(self, exc, context):
        self._close_uart()
        with self._lock:
            self.status = 'error'
        self.get_logger().error(
            f'{context}: {exc}. Check {self.servo_port}, USB connection, and that no other process is using the port.'
        )

    def _stop_motor(self, reason='Stopping launcher motor'):
        if self.uservo is None:
            return False

        self.get_logger().info(reason)
        with self._serial_lock:
            self.uservo.dc_stop(self.servo_id)
            time.sleep(0.02)
            self.uservo.dc_stop(self.servo_id)
        return True

    def _connect_servo(self):
        if self.uservo is not None:
            return True

        self._close_uart()
        try:
            uart = serial.Serial(
                port=self.servo_port,
                baudrate=self.servo_baud,
                parity=serial.PARITY_NONE,
                stopbits=1,
                bytesize=8,
                timeout=0,
                exclusive=True,
            )
            uservo = UartServoManager(uart, servo_id_list=[self.servo_id])
            if uservo.servo_info_dict.get(self.servo_id, None) and uservo.servo_info_dict[self.servo_id].is_online:
                self.get_logger().info(f'Servo ID {self.servo_id} detected and online.')
            else:
                self.get_logger().warn(f'Servo ID {self.servo_id} did not respond to ping.')
            # Mechanical constraint: servo must only rotate CW to reach init position.
            # Use DC mode to spin CW and poll CURRENT_POSITION until we hit INIT_POSITION.
            uservo.set_motor_mode(self.servo_id, MOTOR_MODE_DC)
            time.sleep(0.1)
            uservo.torque_enable(self.servo_id, True)
            time.sleep(0.1)
            uservo.dc_rotate(self.servo_id, DC_DIR_CW, 30)  # slow CW spin
            t_start = time.time()
            while time.time() - t_start < 3.0:  # max 3s to find init pos
                pos = uservo.read_data_by_name(self.servo_id, "CURRENT_POSITION")
                if pos is not None and abs(pos - INIT_POSITION) < 30:
                    break
                time.sleep(0.02)
            uservo.dc_stop(self.servo_id)
        except serial.SerialException as exc:
            self._handle_serial_failure(exc, 'Unable to initialize launcher serial link')
            return False

        self.uart = uart
        self.uservo = uservo
        with self._lock:
            self.status = 'idle'
        self.get_logger().info(
            f'Connected to launcher servo on {self.servo_port} at {self.servo_baud} baud.'
        )
        return True

    def _ensure_servo_connection(self):
        if self.uservo is None:
            self._connect_servo()

    def publish_status(self):
        msg = String()
        msg.data = self.status
        self.status_pub.publish(msg)

    def _request_fire(self):
        if self.uservo is None and not self._connect_servo():
            return False, 'Launcher serial link is unavailable.'

        with self._lock:
            if self.status != 'idle':
                return False, f'Launcher is {self.status}.'
            self._stop_requested.clear()
            self.status = 'firing'  # claim the launcher before releasing the lock

        self.get_logger().info('Firing ball...')
        # Run the motor in a background thread so we don't block ROS callbacks
        # (time.sleep inside a callback would freeze the whole node)
        threading.Thread(target=self._fire_thread, daemon=True).start()
        return True, 'Fire request accepted.'

    def _request_stop(self):
        self._stop_requested.set()

        with self._lock:
            is_firing = self.status == 'firing'

        if self.uservo is None and not self._connect_servo():
            return False, 'Launcher serial link is unavailable.'

        try:
            if self._stop_motor('Manual stop requested for launcher motor'):
                with self._lock:
                    self.status = 'idle'
                self.publish_status()
        except serial.SerialException as exc:
            self._handle_serial_failure(exc, 'Launcher serial communication failed during manual stop')
            return False, 'Launcher stop failed due to serial error.'

        if not is_firing:
            self._stop_requested.clear()
            self.get_logger().info('Launcher was already idle; stop command sent anyway.')
            return True, 'Launcher was already stopped.'

        self.get_logger().info('Launcher stop requested during active firing.')
        return True, 'Launcher stop requested.'

    def handle_fire_request(self, _request, response):
        response.success, response.message = self._request_fire()
        return response

    def handle_stop_request(self, _request, response):
        response.success, response.message = self._request_stop()
        return response

    def _fire_thread(self):
        if self.uservo is None and not self._connect_servo():
            return

        try:
            # Spin motor clockwise at full speed (PWM = 100%)
            with self._serial_lock:
                self.uservo.dc_rotate(self.servo_id, DC_DIR_CW, 100)

            # Keep spinning for FIRE_DURATION seconds to launch the ball
            t_start = time.time()
            while time.time() - t_start < self.fire_duration:
                if self._stop_requested.wait(timeout=0.05):
                    break

            # Stop the motor
            self._stop_motor()
        except serial.SerialException as exc:
            self._handle_serial_failure(exc, 'Launcher serial communication failed during firing')
            return

        if self._stop_requested.is_set():
            with self._lock:
                self.status = 'idle'
            self._stop_requested.clear()
            self.get_logger().info('Launcher stop request completed.')
            return

        # Signal to mission controller that this ball is done
        with self._lock:
            self.status = 'complete'
        self.publish_status()  # push 'complete' immediately, don't wait for the 10 Hz timer

        # Brief pause so mission controller has time to see 'complete' before we go idle
        time.sleep(0.1)

        # # Switch back to servo mode so we can command a specific position
        # self.uservo.set_motor_mode(self.servo_id, MOTOR_MODE_SERVO)
        # time.sleep(0.1)  # small delay for mode switch to settle

        # # Read where the servo ended up and move it back to home position
        # current_pos = self.uservo.read_data_by_name(self.servo_id, "CURRENT_POSITION")
        # self.get_logger().info(f'Post-fire position: {current_pos}, correcting to {HOME_POSITION}')
        # self.uservo.write_data_by_name(self.servo_id, "TARGET_POSITION", HOME_POSITION)

        # # Switch back to DC mode ready for the next shot
        # time.sleep(0.5)  # give servo time to reach home before switching modes
        # self.uservo.set_motor_mode(self.servo_id, MOTOR_MODE_DC)

        with self._lock:
            self.status = 'idle'
        self.get_logger().info('Correction done, launcher idle.')

    def destroy_node(self):
        try:
            self._stop_motor('Stopping launcher motor before shutdown')
        except serial.SerialException:
            pass
        self._close_uart()
        super().destroy_node()


def main(args=None):
    rclpy.init(args=args)
    node = BallLauncherNode()
    rclpy.spin(node)   # blocks here, running callbacks until Ctrl+C
    rclpy.shutdown()


if __name__ == '__main__':
    main()

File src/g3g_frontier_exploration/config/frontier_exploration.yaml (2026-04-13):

frontier_explorer:
  ros__parameters:
    map_topic: /map
    global_frame: map
    robot_base_frame: base_link
    occupied_threshold: 56
    frontier_min_cluster_size: 8
    min_goal_distance: 0.8
    frontier_region_resolution: 0.5
    information_gain_radius: 0.6
    min_information_gain_cells: 2
    frontier_window_radius_cells: 2
    min_frontier_free_neighbors: 3
    max_frontier_occupied_ratio: 0.45
    min_reachable_unknown_cells: 3
    min_frontier_unknown_span: 2
    candidate_clearance_radius: 1
    cluster_fail_limit: 3
    cluster_blacklist_ttl_sec: 15.0
    invalid_goal_blacklist_ttl_sec: 15.0
    encapsulation_check_enabled: true
    encapsulation_occupied_threshold: 45
    encapsulation_confirmation_cycles: 3
    encapsulation_max_unknown_holes: 2
    encapsulation_max_unknown_hole_cells: 6
    planning_rate_hz: 1.0
    progress_rate_hz: 2.0
    goal_timeout_sec: 15.0
    blacklist_ttl_sec: 15.0
    completion_patience_cycles: 5
    autostart: false

post_exploration_traverser:
  ros__parameters:
    map_topic: /map
    exploration_complete_topic: /exploration_complete
    exploration_enable_service: /exploration/set_enabled
    global_frame: map
    robot_base_frame: base_link
    occupied_threshold: 56
    autostart_after_exploration_complete: true
    planning_rate_hz: 0.5
    progress_rate_hz: 2.0
    goal_timeout_sec: 45.0
    sample_spacing: 1.25
    min_goal_distance: 1.0
    max_path_evaluations: 24
    candidate_clearance_radius: 4
    clearance_lookup_radius: 8
    viewpoint_window_radius_cells: 8
    occupied_view_weight: 1.0
    unknown_view_weight: 2.5
    clearance_weight: 0.35
    path_length_weight: 0.8
    revisit_ttl_sec: 180.0
    failed_goal_ttl_sec: 60.0
    revisit_position_resolution: 0.75
    heading_search_radius_cells: 12
    frontier_reactivation_enabled: true
    frontier_reactivation_cycles: 3
    frontier_min_cluster_size: 8
    frontier_candidate_clearance_radius: 1
    frontier_window_radius_cells: 2
    min_frontier_free_neighbors: 3
    max_frontier_occupied_ratio: 0.45
    min_reachable_unknown_cells: 3
    min_frontier_unknown_span: 2

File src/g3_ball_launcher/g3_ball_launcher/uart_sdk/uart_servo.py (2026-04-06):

'''
JOHO串口总线舵机 Python SDK 
--------------------------------------------------
- 作者: 阿凯爱玩机器人@成都深感机器人
- Email: xingshunkai@qq.com
- update by joho
- 更新时间: 2024-04-26
- 2025-08
--------------------------------------------------
'''
import time
import logging
import serial
import struct
from .packet import Packet
from .packet_buffer import PacketBuffer
from .data_table import *

class UartServoInfo:
	'''串口舵机的信息'''
	SERVO_DEADBLOCK = 1 # 舵机死区
	
	def __init__(self, servo_id, lowerb=None, upperb=None):
		self.is_online = False 	 # 电机是否在线 
		self.servo_id = servo_id # 舵机的ID
		self.cur_position = None # 当前位置
		self.target_position = None # 目标位置
		# 位置与角度的变换关系
		self.position2angle_k = 360 / 4096.0
		self.position2angle_b = -180 #角度体系-180°~180°

		self.last_angle_error = None    # 上一次的角度误差
		self.last_sample_time = None    # 上一次的采样时间
		# 内存表数据
		self.data_table_raw_dict = {} # 原始数据 字典类型
		# 内存表写入标志位
		self.data_write_success = False
		# 舵机状态
		self.status = 0 # 舵机状态

	def is_stop(self):
		'''判断舵机是否已经停止'''
		# # 如果没有指定目标角度， 就将其设置为当前角度
		# if self.target_angle is None:
		# 	self.target_angle = self.cur_angle
		# 角度误差判断
		angle_error = self.target_angle - self.cur_angle
		if abs(angle_error) <= self.SERVO_DEADBLOCK:
			return True
		
		if self.last_angle_error is None:
			self.last_angle_error = angle_error
			self.last_sample_time = time.time()
		
		# 角度误差在死区范围以内则判断为已经到达目标点
		
		# 更新采样数据
		if abs(self.last_angle_error - angle_error) > 0.2:
			self.last_angle_error = angle_error
			self.last_sample_time = time.time() # 更新采样时间

		if (time.time() - self.last_sample_time) > 1:
			# 已经有1s没有更新误差了, 舵机卡住了
			self.last_angle_error = None
			self.last_sample_time = None
			return True
		
		return False

	def position2angle(self, position):
		'''位置转化为角度'''
		return self.position2angle_k * position + self.position2angle_b
	
	def angle2position(self, angle):
		'''角度转换为位置'''
		return (angle-self.position2angle_b)/self.position2angle_k
		#pass

	@property
	def cur_angle(self):
		return self.position2angle(self.cur_position)

	@property
	def target_angle(self):
		return self.position2angle(self.target_position)

	def move(self, target_position):
		'''设置舵机的目标角度'''
		# 设置目标角度
		self.target_position = target_position

	def update(self, cur_position):
		'''更新当前舵机的角度'''
		self.cur_position = cur_position
	
	def __str__(self):
		return "目标角度:{:.1f} 实际角度:{:.1f} 角度误差:{:.2f}".format(self.target_angle, self.cur_angle, self.target_angle-self.cur_angle)

class UartServoManager:
	'''串口总线舵机管理器'''
	# 数据帧接收Timeout
	RECEIVE_TIMEOUT = 0.02		# 接收超时延迟
	RETRY_NTIME = 10 			# 通信失败后，重试的次数
	DELAY_BETWEEN_CMD = 0.001	# 数据帧之间的延时时间
	# 命令类型定义
	CMD_TYPE_PING = 0x01		# 查询
	CMD_TYPE_READ_DATA = 0x02	# 读
	CMD_TYPE_WRITE_DATA = 0x03	# 写
	CMD_TYPE_REG_WRITE = 0x04	# 异步写
	CMD_TYPE_ACTION = 0x05		# 执行异步写
	CMD_TYPE_RESET = 0x06		# 回复出厂设置
	CMD_TYPE_SYNC_WRITE = 0x83	# 同步写
	# 电机控制
	POSITION_DEADAREA = 10		# 舵机位置控制 死区 	 
	def __init__(self, uart, servo_id_list=[1]):
		'''初始化舵机管理器'''
		self.uart = uart						# 串口
		self.pkt_buffer = PacketBuffer()		# 数据帧缓冲区
  		# 创建舵机信息字典
		self.servo_info_dict = {}				# 舵机信息字典
		# 舵机扫描
		self.servo_scan(servo_id_list)
	
	def receive_response(self):
		'''接收单个数据帧'''
  		# 清空缓冲区
		self.pkt_buffer.empty_buffer()
		# 开始计时
		t_start = time.time()
		while True:
			# 判断是否有新的数据读入
			buffer_bytes = self.uart.readall()
			if buffer_bytes is not None and len(buffer_bytes) > 0:
				for next_byte in buffer_bytes:
					self.pkt_buffer.update(next_byte)
			# 弹出接收的数据帧
			if self.pkt_buffer.has_valid_packet():
				# 获取数据帧
				packet_bytes = self.pkt_buffer.get_packet()
				# 提取数据帧参数
				result = Packet.unpack(packet_bytes)
				servo_id, data_size, servo_status, param_bytes = result
				# 舵机状态自动同步
				if servo_id in self.servo_info_dict.keys():
					self.servo_info_dict[servo_id].status = servo_status
				return packet_bytes
			# 超时判断
			if time.time() - t_start > self.RECEIVE_TIMEOUT:
				return None

	def send_request(self, servo_id, cmd_type, param_bytes, wait_response=False, retry_ntime=None):
		'''发送请求'''
		if wait_response:
			# 清空串口缓冲区
			self.uart.readall()

		packet_bytes = Packet.pack(servo_id, cmd_type, param_bytes)	

		if not wait_response:
			# 发送指令
			self.uart.write(packet_bytes)
			time.sleep(self.DELAY_BETWEEN_CMD)
			return True, None
		else:
			
			if retry_ntime is None:
				retry_ntime = self.RETRY_NTIME
			# 尝试多次
			for i in range(retry_ntime):
				self.uart.write(packet_bytes)
				time.sleep(self.DELAY_BETWEEN_CMD)
				response_packet =  self.receive_response()
				if response_packet is not None:
					return True, response_packet
			# 发送失败
			return False, None

	def find_servo(self):
		'''搜索舵机'''
		ret, response_packet = self.send_request(254, self.CMD_TYPE_PING, b'', wait_response=True, retry_ntime=3)
		if ret:
		# 提取读取到的数据位
			servo_id, data_size, servo_status, param_bytes = Packet.unpack(response_packet)
			return True, servo_id
		else:
			return False, None

	def ping(self, servo_id):
		'''舵机通讯检测'''
		ret, response_packet = self.send_request(servo_id, self.CMD_TYPE_PING, b'', wait_response=True, retry_ntime=3)
		if ret and servo_id not in self.servo_info_dict.keys():
			# 创建舵机对象
			self.servo_info_dict[servo_id] = UartServoInfo(servo_id)
			# 舵机角度查询
			# TODO?
		return ret
	
	def read_data(self, servo_id, data_address, read_nbyte=1):
		'''读取数据'''
		param_bytes = struct.pack('>BB', data_address, read_nbyte)
		ret, response_packet = self.send_request(servo_id, self.CMD_TYPE_READ_DATA, param_bytes, wait_response=True)
		if ret:
			# 提取读取到的数据位
			servo_id, data_size, servo_status, param_bytes = Packet.unpack(response_packet)
			return True, param_bytes
		else:
			return False, None
	
	def write_data(self, servo_id, data_address, param_bytes):
		'''写入数据'''
		param_bytes = struct.pack('>B', data_address) + param_bytes
		self.send_request(servo_id, self.CMD_TYPE_WRITE_DATA, param_bytes)
		return True

	def read_data_by_name(self, servo_id, data_name):
		'''根据名字读取数据'''
		# 获取地址位与数据类型
		if data_name not in UART_SERVO_DATA_TABLE:
			return None
		data_address, dtype = UART_SERVO_DATA_TABLE[data_name]
		read_nbyte = 1
		if dtype in ['h', 'H']:
			read_nbyte = 2
		ret, param_bytes = self.read_data(servo_id, data_address, read_nbyte=read_nbyte)
		if not ret:
			return None
		# 数据解析
		value = struct.unpack(f">{dtype}", param_bytes)[0]
		return value

	def write_data_by_name(self, servo_id, data_name, value):
		'''根据名称写入数据'''
		if data_name not in UART_SERVO_DATA_TABLE:
			return None
		data_address, dtype = UART_SERVO_DATA_TABLE[data_name]
		param_bytes = struct.pack(f">{dtype}", value)
		self.write_data(servo_id, data_address, param_bytes)
	
	def get_legal_position(self, position):
		'''获取合法的位置'''
		position = int(position)
		if position > 4095:
			position = 4095
		elif position < 0:
			position = 0
		return position
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

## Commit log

2026-03-17 feat: enable custom world
    [model-1_4.sdf, model.sdf, tb3_sandbox.sdf.xacro]
2026-03-20 feat: add some simple worlds
    [shapes.sdf, tutorial_world.sdf, warehouse_world.sdf]
2026-03-21 feat: isolate the robot sdf
    [tb.sdf.xacro]
2026-03-21 feat: actual robot's launch file
    [tb_origin.sdf.xacro]
2026-03-21 feat: docker - switch to use osrf/ros:jazzy-desktop
2026-04-02 feat: add ArUco visual servo docking package (g3_visual_servo)
    Self-contained CV package for RPi deployment. Detects ArUco marker ID 42,
    solves pose via PnP, and executes a multi-state docking maneuver.
    No simulation dependencies — suitable for sparse checkout on RPi.
2026-04-02 feat: sim improvements, Docker fixes, repo cleanup
    - Add side + RGB cameras to robot model (tb.sdf.xacro)
    - Add sim_only_launch.py, square_room world, ArUco marker 42 model
    - Add macOS Docker Compose + devcontainer + FastDDS configs
    - Fix DDS communication (remove restrictive FASTRTPS profile)
    - Fix TURTLEBOT3_MODEL default: burger → waffle
    - Decouple g3gzsim from g3g_frontier_exploration (package.xml)
    - Gitignore local dev tools (sim_dashboard, scripts, DDS fix dirs)
    [model.sdf, square_room.sdf, tb.sdf.xacro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]
2026-04-02 fix: update ArUco marker size to 16.5cm to match printed marker
2026-04-02 fix: update camera topics to /image_raw and /camera_info
2026-04-02 fix: use usb_cam namespaced topics for camera
2026-04-03 add uart servo sdk source code
2026-04-03 add servo correction mechanism, to be tested
    [ball_launcher_node.py]
2026-04-03 add dependencies for launching servo
2026-04-04 fix: throttle LOCKING to 5Hz and add debug logging for ArUco detection
    Processing 30fps was overwhelming detection in LOCKING state. Added
    frame-rate throttle (200ms interval) and debug logs to diagnose
    marker detection failures.
2026-04-04 fix: rich debug overlay for aruco_debug — boundaries, IDs, pose, tvec
    Shows detected marker outlines (green) and rejected candidates (red),
    plus distance, heading, tvec, and state name on the debug image.
2026-04-04 fix: add cmd_vel publish logging to debug motor commands
2026-04-04 feat: fix exploration stuff on the real robot
    [frontier_exploration.yaml]
2026-04-06 feat: add tmux robot session launcher
    Opens 5 named windows: bringup, camera, foxglove, aruco, shell.
    ArUco window is pre-sourced but not auto-launched — run when ready.
    Usage (on RPi): bash ~/nav_ws/docker/robot_session.sh
    Kill session: tmux kill-session -t robot
2026-04-06 refactor: robot_session — 3 panes in one window, no bringup
    Camera | Foxglove | ArUco in a single even-horizontal layout.
2026-04-06 fix: use TwistStamped for cmd_vel (Jazzy requires stamped messages)
    Switch aruco_dock_node and cmd_vel_test from Twist to TwistStamped to
    match enable_stamped_cmd_vel: true in nav2 config and turtlebot3 Jazzy driver.
2026-04-06 docs: add ArUco visual servo docking setup section to README
2026-04-06 fix: disable pseudo-strafe (camera is centred, strafe caused rightward offset)
2026-04-06 feat: add turn_calibrate smoke test for open-loop angle calibration
2026-04-06 update stop for dc motor for servo
2026-04-07 fix: ArUco dock active-target bug + mission controller updates
    - Fix _active_target_id being cleared by _reset() in _activate_docking
    - Preserve active target on FAILED→retry via _reset_once
    - Mission Controller 2.0 updates
2026-04-08 refactor: rewrite aruco dock node with closed-loop PI control
    Replace 8-state open-loop step-and-correct FSM (579 lines) with 4-state
    closed-loop proportional-integral controller (~260 lines). Every camera
    frame computes bearing and distance error, outputs cmd_vel directly.
    No timers, no blind driving, no settle waits.
    - IDLE/SCANNING/APPROACHING/DONE replaces SEARCHING/LOCKING/STEP_SETTLE/
    STEP_TURN/STEP_DRIVE/VERIFY/DONE/FAILED
    - EMA smoothing instead of 8-sample locking phase
    - PI control with integral term to overcome static friction
    - Graceful lost-marker handling (hold -> stop -> back to scanning)
    - Fix mission_controller_stub to explicitly call dock services
    - Add marker 67 model a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
    [model.sdf, warehouse_world.sdf]
2026-04-08 fix: use solvePnP instead of solvePnPGeneric to avoid OpenCV 4.6 segfault
    solvePnPGeneric segfaults on OpenCV 4.6 (Debian container). Switch to
    solvePnP which returns a single solution directly. Also ensure all
    arrays passed are contiguous float64 and wrap in try/except.
2026-04-08 debug: add print markers to find segfault location in aruco detection
2026-04-08 chore: remove debug prints from aruco_dock_node
    Segfault resolved — was caused by using new-style aruco API on OpenCV
    4.6. Legacy API (Dictionary_get) fixes it. Clean up debug prints.
2026-04-08 fix: publish TwistStamped on /cmd_vel instead of Twist
    The TurtleBot3 Gazebo plugin subscribes to TwistStamped, not Twist.
    Type mismatch caused the robot to ignore all velocity commands.
2026-04-08 fix: reverse drive commands for rear-mounted camera
    Camera is on the back of the robot. Negate linear_x (drive backward
    toward marker) and flip angular_z sign (mirror bearing correction).
2026-04-08 fix: correct rear-camera steering to keep marker in view
    Positive angular steers the rear toward the marker instead of away.
    Remove bearing gate on driving — always reverse while steering so
    the rear camera maintains line of sight.
2026-04-08 fix: revert to front-mounted camera commands
    Camera moved back to the front. Positive linear (drive forward),
    negative angular proportional to bearing (turn to face marker),
    bearing gate on driving (align first if >15deg off).
2026-04-10 add initialization position and servo mode handling in BallLauncherNode
2026-04-11 update more led hits for debug
2026-04-12 update servo init position to 3000 and only in clockwise
2026-04-13 feat: replace Nav2 navigation with simple_aruco_dock visual servo
    Remove NAVIGATE_TO_A/B states and Nav2 dependency. The FSM now
    transitions directly from EXPLORE to DOCK, calling /aruco_dock/dock_to_a
    or /aruco_dock/dock_to_b on the simple_aruco_dock node which handles the
    full visual-servo approach. Dock service is triggered on state entry with
    retry logic. Post-dock maneuvers are cancelled via /aruco_dock/scan
    before handing off to aligners. Stale /aruco_dock/done messages are
    ignored outside DOCK states.
2026-04-13 feat: merge nav2 docking system into main
    Squash merge of feat/nav2-docking. Adds:
    - ArUco visual servo docking (simple_aruco_dock) with PI control,
    post-dock turn (wall-parallel via marker normal), and post-shift
    (camera pivot correction)
    - Simple mission FSM (explore → detect marker → dock → done)
    - Station A/B services (dock_to_a, dock_to_b, scan)
    - Nav2 parameter tuning for docking
    - Upstream-compatible aruco_dock interface
    [model.sdf]
2026-04-14 fix: publish done only after post-turn and post-shift complete
    Previously _finish() published /aruco_dock/done before starting the
    post-turn, so the FSM would immediately cancel the post-dock sequence.
    Now: approach done → post-turn → post-shift → publish done.
    If any step is skipped, the chain falls through correctly.
    Also removed the FSM's _call_dock_scan() that was killing post-dock.
2026-04-14 feat: publish station poses continuously instead of one-shot
    Dock node now publishes /station_a_pose and /station_b_pose every
    frame when the marker is visible, not just once. FSM always stores
    the latest pose but only sets "found" on first detection. Removes
    _station_reported one-shot gating and latched QoS.
2026-04-14 fix: negate linear velocity in dock node to match robot direction
2026-04-14 Revert "fix: negate linear velocity in dock node to match robot direction"
    This reverts commit 999ee1e74ea364eb73f76d736a61651a4406dd74.
2026-04-14 fix: reset dock node on re-approach instead of rejecting, cancel timers on finish
    Prevents FSM loop where dock service returns "Already docking" failure,
    causing FSM to cycle through DOCK→ALIGN→failure→DOCK while the dock
    node stays stuck in APPROACHING publishing stale angular velocity.
2026-04-14 fix: change FSM cmd_vel publisher from Twist to TwistStamped
    FSM was creating a Twist publisher on /cmd_vel while Nav2 and dock node
    use TwistStamped — type conflict on the same topic broke cmd_vel delivery.
2026-04-14 fix: strip handle_dock to bare minimum — call once, wait for done, transition
    No periodic logs, no failure paths, no service response callbacks during dock.
2026-04-14 fix: increase bearing tolerance from 3deg to 15deg
    Bearing is near-zero in practice since the marker must be in FOV to be
    detected, making tight tolerance just a source of dwell failures.
2026-04-14 fix: remove bearing from docking done condition — distance only
2026-04-14 fix: only transition to dock when station is within 1m
    Prevents the FSM from starting docking when the marker is first
    spotted far away — waits until the robot is close enough.
2026-04-14 fix: restore camera pivot correction in post-shift distance formula
    Accounts for both lateral offset and camera forward offset sweep
    during the turn, so camera ends up at the marker's position.
2026-04-19 Added bot pictures, demo, CAD files and drawings
    [Feeder Clamp 0.5.SLDPRT, Feeder Clamp.SLDPRT, Feeder.SLDPRT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]
2026-04-19 chore: track mp4 files with Git LFS
